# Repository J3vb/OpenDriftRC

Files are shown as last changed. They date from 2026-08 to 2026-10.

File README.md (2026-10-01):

<p align="center">
  OpenDrift
</p>

OpenDrift is an open source drift gyro for RC drift cars, built around the Waveshare ESP32-S3 Touch AMOLED 1.64 board. It reads steering, throttle, and optional gain channels from a receiver, mixes driver steering with gyro correction, outputs steering and optional throttle signals, and exposes tuning through both the onboard touch UI and a WiFi web configurator.

OpenDrift v1.0 uses a dedicated selectable-rate control task, a single gyro filter, continuous yaw prediction, throttle-informed load-change prediction, and non-accumulating quiet-drift reference feedback. The goal is to make gyro setup less of a black box while keeping the active control path small enough to reason about.

See the current [Technical Tuning Reference](OpenDrift/docs/Tuning.md) for the setup order, symptom table, surface-profile workflow, and findings from real track testing. The public [tuning guide](https://opendriftrc.com/tuning/) provides the shorter trackside workflow.

## Install Firmware

Visit [opendriftrc.com](https://opendriftrc.com) for the project overview, [wiring reference](https://opendriftrc.com/wiring/), and Open Beta firmware. The [browser installer](https://opendriftrc.com/flash/) provides current AMOLED images with either PWM or CRSF receiver support, without an account, source compilation, or command-line tools. Historical round-display releases remain available but are frozen.

## Current Features

- ESP32-S3 firmware using PlatformIO and Arduino.
- 280 x 456 AMOLED touch UI with swipeable pages and a permanent built-in
  background fallback.
- Up to 16 persistent custom AMOLED backgrounds, selectable from the display
  or web configurator. JPG, PNG, and WebP images can be converted locally at
  [opendriftrc.com/backgrounds](https://opendriftrc.com/backgrounds/).
- Persistent AMOLED theme engine with light/dark text, seven accent palettes,
  and background-aware translucent control panels, based on work contributed
  by [J3vb](https://github.com/J3vb).
- Dedicated 250 Hz or 333 Hz IMU/control/steering task isolated from UI, WiFi, and logging work.
- Continuous yaw-acceleration prediction with throttle-informed look-ahead.
- Quiet-drift reference feedback that yields to driver steering and throttle changes.
- Receiver steering input.
- Optional receiver throttle sensing with automatic Performance Mode behavior.
- Receiver gyro gain input.
- Selectable GPIO 18 gyro-gain input or throttle passthrough output.
- Servo output with center, reverse, and travel settings.
- Servo quiet band for direct-drive steering buzz.
- Physical servo endpoint calibration for max left, center, and max right.
- Separate radio steering travel limit.
- Separate servo reverse and gyro reverse.
- Gyro tuning:
  - gain
  - deadband
  - maximum correction
  - smoothing
  - Drift Memory and limit
  - Hold Assist
  - Prediction
  - Countersteer Assist
  - Transition Speed
  - Driver Priority
  - Anti Wobble
- Up to 12 persistent named surface/driving profiles.
- Scrollable trackside profile selection on both displays.
- Do-nothing signal-loss behavior when steering input is lost.
- WiFi access point.
- Browser-based web configurator.
- Non-blocking PSRAM blackbox logging with controller, prediction, throttle, notch, chassis-motion, and correction telemetry.
- Persistent settings stored in ESP32 preferences.
- Transition Speed adjustment centered at the neutral baseline of `50`.
- Driver Priority adjustment that yields fast direct gyro gain as steering input increases; default `0` preserves the established response.
- Phase-aware Anti Wobble notch with a track-tested default of `50`.
- Separate PWM and full-duplex CRSF targets for Waveshare AMOLED V1 and V2.
- Full-duplex CRSF steering, throttle, gain, link statistics, parameter
  telemetry, neutral failsafes, and [EdgeTX tuning](https://github.com/doublej380-pixel/OpenDriftRC/releases/download/v1.0.8/OpenDrift.lua).
- CRSF channel routing to accessory PWM outputs: GPIO 1–8 on AMOLED V1 and
  GPIO 3–8 on AMOLED V2.

## Hardware Routing

### Supported Boards

The **Waveshare ESP32-S3 Touch AMOLED 1.64** is the final and primary OpenDrift hardware target. New development, UI work, and release testing target this board.

Waveshare ships V1 and V2 revisions that require different firmware. V1 has its version silkscreen at the top of the PCB and uses LCD_CS on GPIO 9. V2 has the silkscreen beside the right-side pin headers and uses LCD_CS on GPIO 46. Select the exact revision in the web flasher.

The older Waveshare 1.28-inch round display build is deprecated and frozen. Its PlatformIO environment and implementation remain in the repository for experimentation, but no new firmware releases or feature-parity work are planned.

AMOLED V1 and the Round board use this PWM pinout:

| Signal | GPIO | Direction | Notes |
| --- | ---: | --- | --- |
| Receiver steering / servo in | 15 | Input | Standard RC PWM input |
| Receiver throttle / throttle in | 16 | Input | Throttle sensing and blackbox input |
| Steering servo / servo out | 17 | Output | Stabilized steering command |
| Gain input / throttle output | 18 | Selectable | Gain-channel input by default, or throttle passthrough output |

GPIO 18 cannot provide throttle output and read receiver gain at the same time.
To keep throttle sensing and gain adjustment, split the receiver throttle
signal to GPIO 16 and the ESC rather than plugging the ESC into OpenDrift.

Make sure the receiver, ESP32 board, and servo power system share ground.

AMOLED V2 keeps receiver steering on GPIO 15 and throttle on GPIO 16, but moves steering output to GPIO 1 and the switchable gain/throttle connection to GPIO 2. Do not use GPIO 17/18 for OpenDrift signals on V2; Waveshare connects those pins to IMU_INT2 and TP_INT.

CRSF targets repurpose the receiver pins:

| Signal | GPIO | Direction | Notes |
| --- | ---: | --- | --- |
| CRSF receiver TX | 17 | Input | Native CRSF channel and link frames |
| CRSF receiver RX | 18 | Output | Full-duplex parameter telemetry |
| Steering servo / servo port | 15 | Output | Selectable 250/333 Hz servo PWM |
| ESC throttle / throttle port | 16 | Output | Standard 50 Hz ESC PWM with active-neutral failsafe |

AMOLED V2 instead uses GPIO 1 for CRSF RX and GPIO 2 for CRSF TX while retaining GPIO 15 steering-servo output and GPIO 16 ESC output. All CRSF targets use the same full-duplex implementation and the
separate `OpenDriftCRSF` settings namespace and do not overwrite a PWM tune.

CRSF builds can also mirror any receiver channel to accessory outputs from the
WiFi web configurator. AMOLED V1 exposes GPIO 1–8; AMOLED V2 exposes GPIO 3–8
because GPIO 1/2 carry CRSF. Each enabled pin emits standard 50 Hz receiver PWM
and returns to 1500 microseconds when the CRSF link is lost. These are 3.3 V
signal outputs only: power lights and accessories separately and share ground.

Throttle sensing is not required for basic stabilization, but it is strongly recommended. With the throttle signal connected, OpenDrift can release settled-drift features during power changes instead of inferring those events from yaw alone. Treat it like a sensored-motor cable: the fallback works without it, while Performance Mode has substantially better phase awareness.

The servo should be powered from a suitable BEC or ESC receiver rail. Do not rely on the ESP32 board to power a steering servo. A DIY installation must feed the display/development board regulated 5 V, never an unregulated or 6 V-plus BEC output. The OpenDrift daughter boards under development include an onboard regulator. ESP32-S3 GPIOs are 3.3 V signal pins and are not 5 V tolerant.

## Build And Upload

The firmware project is in:

`OpenDrift/`

## Custom AMOLED Backgrounds

OpenDrift keeps the built-in galaxy image in firmware and can additionally
store up to 16 user backgrounds in the board's FFat partition. Custom images
must be 456 x 280 raw RGB565 files; the browser-based
[background converter](https://opendriftrc.com/backgrounds/) creates the exact
format locally from JPG, PNG, or WebP files.

To install one, join the gyro's `OpenDrift` WiFi network, open
`http://192.168.4.1`, and use the **AMOLED Backgrounds** card. Uploaded images
can be selected or deleted there, and can also be selected from the
**Backgrounds** page on the AMOLED display. Keep the car stationary while an
image is being written to flash. Leaving the selection on **Built-in** uses the
factory background and consumes no additional storage.

Build with PlatformIO:

```sh
pio run
```

The default environment is `waveshare_amoled_164`. Build or upload it explicitly with:

```sh
pio run -e waveshare_amoled_164
pio run -e waveshare_amoled_164 -t upload
```

The custom PlatformIO board definition is included at `OpenDrift/boards/waveshare_amoled_164.json`.

AMOLED V2 uses separate targets:

```sh
pio run -e waveshare_amoled_164_v2
pio run -e waveshare_amoled_164_v2_crsf
```

The frozen round-board environment remains available for local experimentation:

```sh
pio run -e waveshare_128
```

CRSF builds are intentionally separate:

```sh
pio run -e waveshare_amoled_164_crsf
```

Both supported targets enable full-duplex CRSF, GPIO 16 ESC output, and neutral-hold arming. Telemetry uses GPIO 18 on AMOLED V1 and GPIO 2 on AMOLED V2.

Main dependencies are managed in `OpenDrift/platformio.ini`:

- SensorLib
- LovyanGFX
- ESP32Servo
- CST816S (deprecated round-board build only)

## First Power-On

On boot, OpenDrift initializes:

1. Display
2. Settings
3. IMU
4. Servo output
5. Receiver inputs
6. Touch
7. Gyro calibration
8. WiFi, if enabled
9. UI

Keep the car still during startup so gyro calibration can capture a clean yaw-rate offset.

## Onboard UI Pages

Swipe left/right to move between pages.

### Main

Shows the current gyro gain and provides:

- `- / +`: adjust stored gain when radio gain input is not overriding it.
- `CAL`: recalibrate gyro offset. Use this when the car is sitting still and the gyro seems biased.

### Core

Primary correction limits:

- `Deadband`: yaw-rate zone ignored around zero.
- `MAX CORRECTION`: maximum gyro movement across the full calibrated endpoint-to-endpoint steering span. `50%` equals center-to-endpoint authority; `100%` can override one endpoint to the other.
- `GYRO REV`: reverses only the gyro correction direction.

Use `GYRO REV` when normal steering direction is correct, but the gyro counter-steers the wrong way.

### Response

Fast controller behavior:

- `SMOOTHING`: the software yaw low-pass; `0.00` bypasses it completely.
- `GYRO LPF`: QMI8658 hardware filtering at `24 Hz`, lower-latency `120 Hz`, or `Off` for controlled testing.
- `PREDICTION`: continuous yaw-acceleration look-ahead.
- `SERVO QUIET`: suppresses very small physical servo-command changes.

### Assistance

Slow quiet-drift behavior:

- `COUNTERSTEER`: chooses how much additional steady countersteer OpenDrift carries. Zero preserves the driver-led base response; higher values reduce the steering load on the driver without increasing fast yaw damping.
- `HOLD ASSIST`: controls how firmly the quiet-drift reference is retained.
- `DRIFT MEMORY`: feedback for deviation from a learned quiet-drift reference.

The Drift Memory limit remains available in the web configurator as an advanced limit.

### Tail Response

`TAIL SPEED` is tuned separately from the core v1.0 controls:

- `50` is the Open Beta baseline response.
- Below `50` adds damping during deliberate entries and transitions.
- Above `50` releases some damping so the chassis can rotate faster.
- The effect is reduced in a settled drift and cannot reverse gyro correction.

Keep it at `50` unless deliberately collecting same-car experimental A/B data.

`SMOOTH` is intentionally inverted from raw filter math: higher numbers mean more smoothing and slower gyro response.

Deadband is applied as a soft deadband. Small yaw noise is still ignored, but correction fades in from zero instead of jumping as soon as yaw crosses the deadband value.

Conservative first-power values:

| Setting | Start |
| --- | ---: |
| Gain | 1.50 |
| Deadband | 4.0 |
| Max correction | 100% |
| Smoothing | 0.01 |
| Countersteer Assist | 100 |
| Driver Priority | 0 |
| Drift memory | 0.00 |
| Memory limit | 80 |
| Hold Assist | 0 |
| Prediction | 0 |

Tune symptoms:

| Symptom | Try |
| --- | --- |
| Weaves left/right driving straight | Increase deadband or lower gain |
| Initial response is strong but runs out of authority | Raise Max Correction carefully |
| Fast response overshoots | Add Prediction in steps of 5 |
| Prediction makes transitions nervous | Lower Prediction |
| Car is stable but the driver carries too much countersteer | Raise Countersteer Assist in steps of 10 |
| Gyro feels too hands-on during a settled drift | Lower Countersteer Assist |
| High gain feels restrictive near full steering | Add Driver Priority in steps of 5; start below 20 |
| Long drift slowly wanders | Add Hold Assist, then minimal Drift Memory |
| Transition carries the old drift | Lower Hold Assist or Drift Memory |
| Mid-drift wheel oscillation | Lower gain first; verify servo and chassis |
| Feels slow or lazy | Lower smoothing slightly or raise gain |

### Radio

Live receiver monitor:

- Steering pulse and signal state.
- Gain pulse and signal state.
- Current gain value.
- Calibration values.
- Position bars for steering and gain.

Use this page to confirm the receiver is connected and moving through a sensible range.

In a CRSF build the monitor shows channel 1 steering, channel 2 throttle, and
channel 3 gain decoded from the digital link.

### Steering

Steering output setup:

- `TRV`: scales driver steering input without reducing gyro correction authority.
- `REV`: reverses physical servo direction.
- Swipe once more to open the dedicated **Physical Endpoints** page.

### Physical Servo Endpoints

The calibration page uses three large capture buttons. Each button starts red
and turns green after it has captured the servo's actual physical PWM position:

- `MAX LEFT`: position the wheels at their safe physical left stop, then capture it.
- `CENTER`: capture the transmitter at neutral.
- `MAX RIGHT`: position the wheels at their safe physical right stop, then capture it.

OpenDrift saves the calibration after all three physical positions are captured
on opposite sides of center. The saved endpoints become the final asymmetric
servo map and hard clamp, so neither the driver nor gyro can push through them.

CRSF users can perform the same three captures from the EdgeTX `OpenDrift.lua`
tool. Calibration state is persistent and shared: completing it on the radio
turns the AMOLED buttons green, while completing it on the display updates the
radio's `Endpoints` status to `YES`.

Suggested calibration flow:

1. Set servo direction first, then use steering/transmitter endpoint adjustment to position the wheels at the safe physical left stop and tap `MAX LEFT`.
2. Release steering to neutral and tap `CENTER`.
3. Position the wheels at the safe physical right stop and tap `MAX RIGHT`.
4. Confirm all three buttons are green and the page says `SAVED - TAP TO RESET`.
5. Return to Steering and verify the wheels remain inside both saved physical stops.

Changing `REV`, Servo Center, or Servo Travel after calibration deliberately
clears the saved calibration because those changes alter the physical output map.

Servo reverse and gyro reverse are separate on purpose:

- Use `REV` on the Steering page when driver steering moves the wheels backward.
- Use `GYRO REV` on the Gyro page when driver steering is correct but gyro correction is backward.

Physical endpoint calibration and steering travel are separate on purpose:

- Use `MAX LEFT`, `CENTER`, and `MAX RIGHT` to set the servo's physical output limits.
- Use `TRV` to scale driver steering without reducing gyro authority.
- Use Max Correction to select how much of the calibrated physical range the gyro may command.

### WiFi

Shows the network name, WiFi state and connected client count.

- `WIFI ON/OFF`: toggles the access point.

When WiFi is enabled, connect to the network shown at the top of the page and
open `http://192.168.4.1/`. The password is `opendrift`.

- A unit on the default name broadcasts `OpenDrift-XXXX`. The last four
  characters are unique to the board, so several cars at one track show up as
  separate networks. A custom name from the web configurator is used as is.
- At startup, OpenDrift picks the quietest of channels 1, 6 and 11. It uses a
  narrow 20 MHz channel so 2.4 GHz RC links clash with it less often.
- WiFi stays on for at least 3 minutes after power-on while waiting for the
  first phone. After that, the auto-off timeout applies.
- Phones may warn that the network has no internet. Choose to stay connected,
  or turn off mobile data while configuring.

### System

Basic firmware/system information. Tap the GPIO 18 mode button to switch between `GAIN INPUT` and `THROTTLE OUT`.

### Profiles

The Profiles page lists the driving profiles created in the web configurator. Tap a profile to activate its complete driving tune. Swipe vertically when more than four profiles exist; the list supports up to 12 profiles.

Profiles save gain, deadband, max correction, smoothing, Prediction, Countersteer Assist, Driver Priority, Hold Assist, Drift Memory and its limit, and radio steering travel. Trackside adjustments automatically save back to the active profile.

Hardware and installation settings remain global, including gyro/servo direction, physical steering endpoints, servo center and travel, WiFi, logging, and GPIO mode. Switching surfaces therefore cannot disturb the car's physical setup.

### Control and servo rate

OpenDrift defaults to **250 Hz** for broad digital-servo compatibility. **333 Hz** reduces the output interval from 4 ms to about 3 ms and can sharpen a fast supported servo, but it must only be used when the servo manufacturer explicitly rates the servo for 333 Hz operation. An unsupported update rate can cause heat, buzzing, erratic steering, or servo damage.

The setting is global and appears on the AMOLED System page, in the web configurator, and in the CRSF/EdgeTX parameter list. Restart OpenDrift after changing it so both the control task and steering PWM start at the selected rate.

## Web Configurator

When WiFi is enabled, OpenDrift starts a web configurator at:

`http://192.168.4.1/`

Current web settings:

- Create named driving profiles from the current tune
- Activate or delete existing profiles
- Gyro gain
- Channel 3 gain minimum / maximum (`0.00-6.00`)
- Deadband
- Reverse gyro correction
- Max correction
- Smoothing
- Prediction strength
- Transition Speed
- Driver Priority
- Anti Wobble
- Drift memory
- Memory limit
- Hold Assist
- Servo reverse
- Servo center
- Servo travel
- Servo quiet band
- Steering max left / center / max right
- Radio steering travel
- Gain channel low / high
- GPIO 18 gain-input or throttle-output mode
- WiFi enabled on boot
- WiFi auto-off timeout
- Blackbox logging enabled
- Raw pitch, roll, acceleration, and surface-disturbance telemetry for chassis analysis

The web page also shows the active profile, live receiver pulse values for steering, throttle, and gain, plus the active GPIO 18 mode.

Use the web configurator when you want to make several changes quickly. Use the onboard UI when tuning trackside without a phone or laptop.

## Onboard Blackbox Log

OpenDrift records fixed-size blackbox samples into a 4 MB circular PSRAM buffer at about 20 Hz while steering receiver signal is present.

Blackbox logging is disabled by default. Enable `Onboard logging` in the web configurator only when you want to collect data, then save settings.

No flash or filesystem writes occur while driving. Once the circular buffer is full, the oldest records are overwritten so the newest behavior remains available. Download the CSV before removing power because PSRAM is volatile.

The web configurator shows the current log size and provides:

- `Download CSV`
- `Clear RAM Log`

Log rows include:

- Time
- Raw yaw rate
- Filtered yaw rate
- Roll and pitch gyro rates (`gyro_x_dps`, `gyro_y_dps`)
- Raw X/Y/Z acceleration in g
- Total acceleration magnitude and high-frequency acceleration delta
- A filtered `surface_disturbance` score from `0.0` to `1.0`
- Requested gyro correction before Max Correction
- Limited gyro correction after Max Correction
- Applied gyro correction after the driver/gyro steering mix
- Correction saturation state
- Steering input and calibrated steering command
- Servo output
- Servo quiet band
- Throttle input
- Gain input and active gain
- Active deadband, max correction, smoothing, Prediction, Countersteer Assist, Driver Priority, Hold Assist, Drift Memory, and memory limit
- Driver Priority scale and effective live direct gain
- Predicted yaw, quiet-drift reference, reference error, steady countersteer contribution, and memory correction
- Driver steering activity and throttle-prediction blend
- Controller phase (`0` idle, `1` entry, `2` settled, `3` transition) and reference-lock blend
- Anti Wobble notch depth, isolated residual, tracked notch frequency, transition-authority blend, and throttle-lift blend
- Steering/throttle/gain signal state and GPIO 18 mode

Suggested test workflow:

1. Connect to the `OpenDrift` WiFi network.
2. Open `http://192.168.4.1/`.
3. Enable onboard logging if it is off, then save settings.
4. Tap `Clear RAM Log`.
5. Drive the car.
6. Reconnect to WiFi and tap `Download CSV` before resetting or removing power.

The CSV can be pasted into a spreadsheet or plotted to see whether the car spun because of delayed correction, overcorrection, max correction saturation, noisy yaw, or steering/radio behavior.

`surface_disturbance` still combines sudden acceleration-vector changes, roll/pitch rate, and low-g unloading indicators for analysis. OpenDrift v1.0 logs it but does not currently apply terrain correction.

## Gyro Algorithm Overview

OpenDrift v1.0 runs this path at the selected 250 Hz or 333 Hz rate:

1. Read receiver steering, throttle, and IMU yaw.
2. Subtract calibrated gyro offset and apply soft deadband.
3. Apply the selected hardware gyro LPF and optional software yaw low-pass.
4. Estimate short-horizon yaw from filtered yaw acceleration.
5. Extend that horizon when throttle predicts application or a longer off-throttle load change.
6. Shape damping briefly during deliberate direction changes without changing the hard correction ceiling.
7. Apply the phase-aware Anti Wobble notch around the tracked 2.5-3.6 Hz wheel-resonance band while preserving slow chassis yaw and useful response outside that band.
8. Convert predicted yaw directly into correction with Gain.
9. Learn a slow yaw reference while driver steering and throttle are quiet.
10. Add optional Countersteer Assist from the slow learned reference only.
11. Apply Drift Memory only to error from that reference.
12. Prevent memory from pushing farther into correction saturation.
13. Limit signed gyro movement to the configured full-span Max Correction
    percentage, then mix it with driver steering and clamp the combined command.
14. Apply the calibrated physical endpoint map as the final hard servo limit.

Driver steering activity and throttle changes make the slow reference yield
immediately. Neither disables the fast direct damping path.

## Signal Loss Behavior

The standard PWM builds retain the existing do-nothing behavior: if steering
input disappears, OpenDrift does not send a new servo command.

This leaves the servo at the last commanded position. It is intentionally a simple do-nothing behavior while failsafe strategy is still being evaluated.

The full CRSF build has deterministic behavior because all channels share one
link state. A channel frame older than 50 ms centers steering and commands
neutral throttle. Throttle remains locked until a valid link has held neutral
for 500 ms after boot or reconnection.

## Tuning

Use the [Technical Tuning Reference](OpenDrift/docs/Tuning.md) rather than tuning every setting at once. The most important lessons from development are:

- Establish a mechanically sound car before blaming the gyro.
- Set the servo's internal anti-wobble only as high as it can run without buzzing; high servo torque/power can amplify internal oscillation.
- Treat Gain as the primary surface-dependent setting and store each surface in a profile.
- Tune entries with Gain, Max Correction, and Smoothing before adding slow reference feedback.
- Add Prediction in small steps only after the direct response is understood.
- Use Hold Assist for sustained-drift reference retention, then add only the minimum Drift Memory required.
- Use Countersteer Assist to choose driver-led versus gyro-led settled drifts without retuning Gain.
- Connect throttle sensing so OpenDrift can anticipate power and load changes.

OpenDrift v1.0 is the first public controller. Start from the conservative
values in the tuning reference and save proven surface setups as profiles.

## Future Work

- **Servo resonance calibration:** add a stationary calibration mode that sweeps a small steering command across a safe frequency range and captures high-rate chassis IMU data. Because the servo is rigidly mounted to the chassis, its buzz and self-oscillation should be measurable without another sensor. The first version should compare vibration energy, dominant resonances, settling, and left/right behavior to help evaluate internal servo anti-wobble, torque, power, and response settings and recommend OpenDrift quiet-band and correction-rate settings. Command shaping or resonance compensation should only follow after repeatable measurements show that it can reduce vibration without adding harmful control-loop delay.

## Project Layout

Important folders:

- `OpenDrift/src/main.cpp`: main firmware loop and control mixing.
- `OpenDrift/lib/GyroController`: gyro filtering and correction generation.
- `OpenDrift/lib/RadioInput`: receiver PWM input capture.
- `OpenDrift/lib/CrsfInput`: bounded native CRSF frame decoding and telemetry.
- `OpenDrift/lib/CrsfParameterDevice`: bidirectional CRSF settings device.
- `OpenDrift/lib/EscOutput`: dedicated 50 Hz LEDC throttle output.
- `OpenDrift/lib/Servo`: servo output wrapper.
- `OpenDrift/lib/Settings`: persistent settings.
- `OpenDrift/lib/UI`: onboard touch UI.
- `OpenDrift/lib/WebConfigurator`: web settings page.
- `OpenDrift/lib/WIFIManager`: WiFi access point control.
- `OpenDrift/lib/Backgrounds`: persistent AMOLED background storage and
  recovery.
- `OpenDrift/docs/Tuning.md`: complete tuning and blackbox interpretation guide.
- `OpenDrift/docs/CRSF-Experimental.md`: CRSF wiring, failsafes, and validation
  workflow.
- `OpenDrift/radio/edgetx`: source for the [OpenDrift EdgeTX tuning tool](https://github.com/doublej380-pixel/OpenDriftRC/releases/download/v1.0.8/OpenDrift.lua).
- `OpenDrift/assets/backgrounds`: built-in AMOLED fallback background data.
- `OpenDrift/boards`: custom PlatformIO board definitions.

## License

See `LICENSE`.

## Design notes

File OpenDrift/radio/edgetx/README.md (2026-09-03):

# [OpenDrift EdgeTX tool](https://github.com/doublej380-pixel/OpenDriftRC/releases/download/v1.0.8/OpenDrift.lua)

This tool supports the AMOLED V1 and V2 **full-duplex** CRSF firmware targets:
`waveshare_amoled_164_crsf` and `waveshare_amoled_164_v2_crsf`.

Download [`OpenDrift.lua`](https://github.com/doublej380-pixel/OpenDriftRC/releases/download/v1.0.8/OpenDrift.lua), copy it to `SCRIPTS/TOOLS/OpenDrift.lua` on the radio SD card,
then launch **OpenDrift** from the [EdgeTX Tools menu](https://github.com/doublej380-pixel/OpenDriftRC/releases/download/v1.0.8/OpenDrift.lua).

CRSF wiring for the full-duplex firmware:

- Receiver TX to OpenDrift GPIO 17
- Receiver RX to OpenDrift GPIO 18
- Receiver and OpenDrift grounds connected

Use the roller to select a setting, press it to enter edit mode, rotate to
change the value, and press again to finish. Changes are applied live and are
saved by OpenDrift's normal delayed settings writer. A successful radio write
also requests an immediate refresh of the current OpenDrift display page.

Physical endpoint calibration sets the servo's hard output limits and is shared with both displays. The header and
`Endpoints` row show `NO`, `PARTIAL`, or `YES`. To calibrate from the radio:

1. Hold the steering at its safe physical left stop, select `Capture Left`, and press Enter.
2. Release to neutral, select `Capture Center`, and press Enter.
3. Hold full right, select `Capture Right`, and press Enter.

The action rows show `HOLD POSITION + ENTER` while selected. After all three
valid captures, the status changes to `YES` and the AMOLED calibration buttons
turn green. Capturing on the AMOLED page updates the radio status as well.
Use `Reset Cal` before expanding or replacing existing endpoints.

`Active Gain` follows CRSF channel 3 live. The tool shows a reminder that
channel 3 overrides gain changes made elsewhere while its signal is valid; the
stored profile gain remains the fallback used without that gain signal.
`CH3 Gain Min` and `CH3 Gain Max` map the full Channel 3 control movement to
the desired gyro-gain range. The default remains `0.50` to `3.00`, while both
the controller and Channel 3 mapping support values up to `6.00`.

The tool exposes the gyro and steering values: Active Gain, Channel 3 gain range, Deadband, Max Correction,
Smoothing, Gyro LPF, Drift Memory, Memory Limit, Hold Assist, Countersteer, Transition
Speed, Prediction, Anti Wobble, Servo Quiet, Steering Travel, physical endpoints,
Servo Travel, Servo Center,
Servo Reverse, and Gyro Reverse. It also assigns CRSF channel 1–16 or OFF to
GPIO 1–8 on AMOLED V1 and GPIO 3–8 on AMOLED V2. GPIO 1/2 display `RES` on V2
because those pins carry the CRSF UART.

`Gyro LPF` selects the QMI8658 hardware filter: `24 Hz` is the original
low-bandwidth mode, `120 Hz` reduces sensor phase delay, and `Off` bypasses the
sensor LPF. `Smoothing 0.00` is a true software-filter bypass. Blackbox logs
record the active selection in `gyro_lpf_mode` as 0, 1, or 2 respectively.

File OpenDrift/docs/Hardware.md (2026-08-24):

# OpenDrift Hardware Notes

## Primary board

The final supported target is the Waveshare ESP32-S3 Touch AMOLED 1.64. The older Waveshare 1.28-inch round display is deprecated and frozen; its existing source remains available for experimentation but receives no new releases or feature-parity work.

The AMOLED board has incompatible V1 and V2 revisions. V1 is marked at the top of the PCB and uses LCD_CS GPIO 9. V2 is marked beside the right-side headers and uses LCD_CS GPIO 46. V2 also connects IMU_INT2 to GPIO 17 and TP_INT to GPIO 18, so OpenDrift does not use GPIO 17/18 for external signals on V2.

## QMI8658 IMU

Both boards use the QMI8658 six-axis IMU. OpenDrift uses body Z as yaw and records body X/Y gyro plus all three accelerometer axes for terrain and load-transfer analysis.

| Board | SDA | SCL |
| --- | ---: | ---: |
| AMOLED 1.64 | GPIO 47 | GPIO 48 |
| Round 1.28 | GPIO 6 | GPIO 7 |

The current board orientation reports clockwise rotation as positive Z and counter-clockwise rotation as negative Z. Always verify correction direction by rotating the complete car before driving.

## PWM receiver and servo routing

AMOLED V1 and the Round build use the same PWM pinout:

| Signal | GPIO | Direction |
| --- | ---: | --- |
| Receiver steering / servo in | 15 | Input |
| Receiver throttle / throttle in | 16 | Input |
| Steering servo / servo out | 17 | Output at selectable 250/333 Hz |
| Gain input or throttle passthrough | 18 | Selectable |

GPIO 18 can be a receiver gain input or an ESC throttle output, but not both.
To retain throttle sensing and receiver gain control simultaneously, split the
receiver throttle signal between GPIO 16 and the ESC instead of connecting the
ESC to GPIO 18.

AMOLED V2 PWM uses GPIO 15 steering input, GPIO 16 throttle input, GPIO 1 steering-servo output, and GPIO 2 as the selectable gain input or throttle output.

## CRSF routing

AMOLED V1 and Round CRSF share this routing:

| Signal | GPIO | Direction |
| --- | ---: | --- |
| CRSF RX from receiver TX | 17 | Input |
| CRSF TX to receiver RX | 18 | Output |
| Steering servo / servo port | 15 | Output at selectable 250/333 Hz |
| ESC throttle / throttle port | 16 | Output at 50 Hz |

Both `waveshare_128_crsf` and `waveshare_amoled_164_crsf` enable the complete
full-duplex path. They remain separate from the normal PWM environments because
the GPIO routing and settings namespace differ.

AMOLED V2 CRSF uses GPIO 1 RX, GPIO 2 TX, GPIO 15 steering-servo output, and GPIO 16 ESC output. Its targets are `waveshare_amoled_164_v2` and `waveshare_amoled_164_v2_crsf`.

CRSF channel mapping is channel 1 steering, channel 2 throttle, and channel 3
gain. A stale channel frame centers steering and commands neutral throttle.
Throttle output requires a valid link and a 500 ms neutral hold
before arming.

## CRSF auxiliary channel outputs

The AMOLED CRSF builds can mirror any CRSF channel from 1 through 16 to a
standard 50 Hz receiver-style PWM signal. Assign each pin independently in the
WiFi web configurator under **Auxiliary Channel Outputs**.

| Board | Available auxiliary GPIOs |
| --- | --- |
| AMOLED V1 CRSF | GPIO 1–8 |
| AMOLED V2 CRSF | GPIO 3–8 |

GPIO 1/2 are unavailable on V2 because they carry the CRSF UART. Disabled pins
remain inputs. Enabled pins output the selected channel and command 1500
microseconds when the CRSF link is lost. GPIOs provide a 3.3 V signal only;
lights, controllers, or other accessories require their own appropriate power
supply and a common ground with OpenDrift.

## Throttle sensing

Throttle sensing is electrically optional and automatically falls back when no valid PWM signal exists. It is strongly recommended for OpenDrift v1.0 because it announces power and chassis-load changes, temporarily extends yaw prediction, and makes the slow drift reference yield before stale feedback can fight the transition.

Only the receiver signal and a shared ground are required. OpenDrift does not power the receiver or ESC through the throttle input.

## Power and grounding

The receiver, ESP32 board, and servo/ESC system must share ground. Power the steering servo from an appropriate BEC or receiver rail; do not draw servo current through the ESP32 board.

Feed a DIY OpenDrift display/development board with regulated 5 V on its 5 V
input. Do not connect a 6 V or higher BEC directly to that input. The OpenDrift
daughter boards under development include an onboard regulator so the builder
does not need to add a separate 5 V regulator. ESP32-S3 GPIOs remain 3.3 V logic
and are not 5 V tolerant; every external GPIO is a 3.3 V signal only.

Fast drift servos can draw large transient current and can oscillate from their own internal settings. Verify servo stability directly from the receiver before diagnosing the gyro.

OpenDrift defaults to 250 Hz for broad digital-servo compatibility. The optional 333 Hz control and servo rate is only for servos whose manufacturer explicitly supports 333 Hz. Restart the board after changing the rate.

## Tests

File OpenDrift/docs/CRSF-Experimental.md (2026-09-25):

# CRSF Open Beta builds

These are separate firmware targets for direct CRSF control. Choose the CRSF
variant only when the receiver is wired through OpenDrift.

## Build target

- `waveshare_amoled_164_crsf`: full-duplex AMOLED target
- `waveshare_amoled_164_v2_crsf`: full-duplex AMOLED V2 target

The Waveshare round-display target is frozen and is no longer part of current
builds or releases.

CRSF settings are stored in the separate `OpenDriftCRSF` NVS namespace, so
they do not overwrite the corresponding PWM tune.

All targets use the complete path: bounded CRSF receive processing, parameter
telemetry, GPIO 16 ESC PWM, deterministic neutral behavior, and the
[EdgeTX tuning tool](https://github.com/doublej380-pixel/OpenDriftRC/releases/download/v1.0.8/OpenDrift.lua). The round target proved stable with a SpeedyBee SB Nano at
the MT12's F1000 packet rate after the receive loop was given an explicit byte
budget; the AMOLED target now uses the same CRSF implementation.

## SpeedyBee SB Nano wiring

Wire the receiver signals crossed, as required by a UART:

| SpeedyBee SB Nano | OpenDrift board | Purpose |
|---|---|---|
| TX | GPIO 17 | CRSF data into OpenDrift |
| RX | GPIO 18 | CRSF data/parameter telemetry from OpenDrift |
| GND | GND | Common signal ground |
| 5V | Vehicle BEC 5V | Receiver power |

That table applies to AMOLED V1. AMOLED V2 uses GPIO 1 for receiver
TX into OpenDrift and GPIO 2 for receiver RX/parameter telemetry. Do not use
GPIO 17/18 for external signals on V2 because Waveshare connects them to
IMU_INT2 and TP_INT.

OpenDrift outputs are:

| OpenDrift board | Connect to | Signal |
|---|---|---|
| GPIO 15 | Steering servo signal | Selectable 250/333 Hz PWM |
| GPIO 16 | ESC throttle signal | 50 Hz PWM |

Do not power the servo or ESC motor from the display board. A DIY display-board
installation needs a regulated 5 V supply; do not feed a 6 V or higher BEC
directly into the board. The daughter boards under development include their
own regulator. Use the vehicle's normal power wiring, make sure every device
shares ground, and verify the connector labels rather than relying on wire
colour or position.

## Initial channel map

- CRSF channel 1: steering
- CRSF channel 2: throttle
- CRSF channel 3: gyro gain

Channel values are decoded from native 11-bit CRSF frames. Existing steering
calibration, travel, gyro processing, web status, and blackbox logging consume
those decoded values through the same interfaces used by the PWM build.

## Auxiliary channel outputs

The local WiFi configurator can assign CRSF channel 1–16 independently to
GPIO 1–8 on AMOLED V1. AMOLED V2 offers GPIO 3–8 because GPIO 1/2 are used by
the CRSF UART. Outputs use standard 50 Hz receiver PWM and command 1500
microseconds on signal loss. They are 3.3 V signal pins, not accessory power
outputs; use external power and a common ground for lights and controllers.

## Failsafes

- A CRSF channel frame older than 50 ms is treated as signal loss.
- Steering centers when the link is lost.
- GPIO 16 emits no throttle PWM until a valid link has held throttle within
  50 microseconds of center for 500 ms.
- If the link is lost, the full build commands neutral throttle immediately.
  Reconnection requires another neutral hold before live throttle passes.

## [EdgeTX parameter tool](https://github.com/doublej380-pixel/OpenDriftRC/releases/download/v1.0.8/OpenDrift.lua)

Download [`OpenDrift.lua`](https://github.com/doublej380-pixel/OpenDriftRC/releases/download/v1.0.8/OpenDrift.lua) and copy it to `SCRIPTS/TOOLS/OpenDrift.lua` on the radio SD
card, then open **OpenDrift** from the [EdgeTX Tools menu](https://github.com/doublej380-pixel/OpenDriftRC/releases/download/v1.0.8/OpenDrift.lua). The current tool reads
and writes the controller settings over full-duplex CRSF:

- saved gain, deadband, Max Correction percentage, and smoothing;
- Drift Memory, memory limit, Hold Assist, and Countersteer Assist;
- Transition Speed, Driver Priority, Prediction, Anti Wobble, Servo Quiet, Steering Travel, Servo Travel,
  and Servo Center;
- Servo Reverse and Gyro Reverse.
- shared physical servo endpoint-calibration status plus live left, center, and
  right capture actions and a Reset Cal action. Captures made from EdgeTX
  immediately update the AMOLED page, and display-side calibration is polled
  back into the radio tool.

Writes are acknowledged over CRSF, applied live, saved through the normal
delayed settings writer, and request an immediate redraw of the current gyro
screen.

The same tool also exposes the auxiliary output map. AMOLED V1 can assign
GPIO 1–8 to CRSF channel 1–16 or Off. AMOLED V2 can assign GPIO 3–8; GPIO 1/2
show as reserved because they carry the CRSF UART.

## Problems found during validation

- An F1000 receiver can keep the UART continuously non-empty. CRSF receive work
  is bounded per update so it cannot starve the selected-rate controller.
- Using the general servo allocator for simultaneous 250 Hz steering and 50 Hz
  throttle exhausted or cross-routed ESP32 timing resources. `EscOutput` now
  owns a dedicated 14-bit LEDC channel for throttle.
- CRSF settings use the `OpenDriftCRSF` NVS namespace so switching firmware
  variants cannot overwrite a PWM profile.

## First bench test

1. Remove the motor pinion or disconnect the motor from the ESC.
2. Flash the CRSF environment matching the connected display board with only
   that board connected by USB.
3. Wire and power the receiver, then bind it to the MT12.
4. Open the USB serial monitor at 115200 baud. The five-second CRSF report
   should show increasing frame counts, low CRC errors, link quality, and
   `throttle=LOCKED`.
5. Confirm steering, throttle, and gain move in the web configurator.
6. Hold throttle neutral for 500 ms and confirm the report changes to
   `throttle=ARMED`.
7. Turn the transmitter off. Steering and throttle must return to neutral and
   the report must return to `throttle=LOCKED`.
8. Open the [EdgeTX tool](https://github.com/doublej380-pixel/OpenDriftRC/releases/download/v1.0.8/OpenDrift.lua), change one harmless value, and confirm both the radio
acknowledgement and gyro-screen refresh.

Only reconnect the motor after every applicable check passes.

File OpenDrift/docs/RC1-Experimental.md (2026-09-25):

# Experimental Transition Response

Transition Speed is a direction-change timing adjustment. Start at `50`.

Unlike the former gain-based response experiment, this adjustment slews the
gyro correction through a direction change without multiplying Gyro Gain.
Driver steering announces the transition and measured chassis yaw keeps the
timing stage active through the physical reversal. Values below 50 reverse
correction more slowly; values above 50 reverse it more quickly. Transition
Speed never changes the hard Max Correction ceiling. It does not command
rotation, reverse gyro direction, or change steady Countersteer Assist.

Transition prediction is also tapered while a direction change is in progress.
If acceleration prediction reaches the new yaw direction before the measured
chassis does, the controller now falls back to continuous measured-yaw damping
instead of briefly dropping correction to zero.

## First test

1. Keep the proven track profile unchanged and set Transition Speed to `50`.
2. Confirm that entries and transitions are predictable with the neutral path.
3. Test `25` for slower rotation and `75` for faster rotation using the same
   entries and transitions. The wide first comparison is intentional.
4. Work back toward `50` in steps of `5` or `10` once the preferred direction
   is obvious.
5. Capture a blackbox log at `50` and at the preferred experimental value.

Compare transition duration, peak yaw rate, overshoot after the direction
change, steering activity, `transition_speed_blend`,
`transition_authority_blend`, and `transition_prediction_scale`. Avoid changing
Gain, Prediction, Hold Assist, or Countersteer Assist during the comparison.

## Blackbox fields

- `transition_speed`: saved correction-reversal speed from 0-100; start at 50.
- `transition_speed_blend`: signed configured speed while transition timing is
  active. Negative values are slower; positive values are faster.
- `transition_slew_us`: actual correction from the gain-independent timing
  stage before Memory and Max Correction.
- `transition_authority_blend`: detected transition envelope from 0 to 1.
- `transition_prediction_scale`: multiplier applied to optional acceleration
  and throttle look-ahead. It approaches 0.25 during a full transition.

## Settled-drift residual damping

Blackbox runs 39 through 47 identified the remaining wheel wobble as a
closed-loop mode centered near 3.2 Hz. Broad residual suppression improved it
around strength 70, but higher values removed useful fast gyro damping and made
the car worse. Control now uses a narrow notch that starts at 3.2 Hz and slowly
tracks confirmed oscillation between 2.5 and 3.6 Hz whenever the car is settled
and driver input is quiet. A deliberate transition or strong steering input
freezes frequency tracking while retaining a shallow guard notch. Suppression
moves smoothly between the transition guard, entry depth, and full settled
depth instead of abruptly releasing the resonant band at each state change.

Anti Wobble is the only control. It defaults to `50`. At `0`, the notch is bypassed. Higher values
increase notch depth, up to the complete tracked-notch response at `100`. Slow
chassis yaw, fast corrections outside the wobble band, Countersteer Assist,
and Prediction remain active. The frequency detector and latch remain in the
blackbox as diagnostic telemetry but do not gate control.

- `hunt_residual_dps`: instantaneous yaw isolated by the tracked notch.
- `hunt_removed_us`: direct correction withheld from that residual.
- `hunt_consistent_half_cycles`: consecutive half-cycles agreeing on frequency.
- `hunt_latch`: remaining confirmed-event hold from 0 to 1.
- `anti_wobble`: saved Anti Wobble notch-depth setting from 0-100.
- `hunt_residual_envelope_dps`: continuous residual-energy diagnostic.
- `hunt_notch_center_hz`: slowly tracked center frequency currently applied
  by the dynamic notch.

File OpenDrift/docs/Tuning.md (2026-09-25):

# OpenDrift v1.0 Tuning

> **Technical reference:** This document records the complete tuning behavior
> and current test workflow. The shorter public guide is available at
> [opendriftrc.com/tuning](https://opendriftrc.com/tuning/).

OpenDrift v1.0 is a clean-sheet controller built from extensive track testing.
It uses a deliberately short control path so each adjustment has a clear job.

OpenDrift v1.0 runs the IMU, control calculation, and steering output in a dedicated
250 Hz or 333 Hz task. Display, touch, Wi-Fi, web configuration, and logging run outside
the control task. The steering servo output uses the same selected rate; throttle passthrough
remains 50 Hz.

## Mechanical baseline first

The controller cannot repair an unstable chassis or servo.

Before tuning:

- Confirm the servo is stable with its internal anti-wobble setting just below
  the point where it buzzes.
- Confirm the receiver has no hidden stability assistance.
- Check steering endpoints for binding.
- Establish sensible front toe, rear toe, camber, ride height, and damping.
- Verify the same chassis can drive cleanly with a known-good gyro.
- Calibrate steering and gyro direction with the wheels safely off the ground.

Open **Physical Endpoints** and position the wheels at their
safe physical full-left stop, neutral, and safe full-right stop before capturing
each point. Each target changes from red to green; do not drive until all
three are green and the page reports `SAVED - TAP TO RESET`. CRSF users can make
the same captures from `OpenDrift.lua`. Its `END: NO/PART/YES` status and the
AMOLED status use the same saved calibration and update each other.

Rear toe-in accidentally present during development made the car and controller
fight one another. Correcting the alignment materially improved both OpenDrift
and commercial gyros.

## v1.0 signal path

The active path is intentionally short:

1. Read receiver steering, throttle, and IMU yaw.
2. Apply deadband and one time-based yaw low-pass.
3. Estimate short-horizon yaw from filtered yaw acceleration.
4. Extend that prediction briefly when throttle announces a chassis-load
   change.
5. Hold a longer prediction envelope after throttle lift so off-throttle load
   changes do not arrive as a surprise.
6. Taper optional prediction during deliberate transitions so prediction does
   not run ahead of the physical yaw reversal.
7. Track and isolate the measured 2.5-3.6 Hz wheel-wobble band during a quiet
   settled drift, then use Anti Wobble to control notch depth while
   preserving slow chassis yaw and useful correction outside that band. A
   shallow guard remains during entry and transitions so the resonance cannot
   restart while frequency tracking is intentionally frozen.
8. Apply direct yaw correction using Gain.
9. While the driver and throttle are quiet, learn a slow drift reference.
10. Add optional Countersteer Assist from that slow reference.
11. Apply Drift Memory only to deviation from that reference.
12. Clamp correction with saturation-aware memory behavior.
13. Add correction to receiver steering and send it to the servo.

Driver steering activity and throttle changes make the slow reference follow
the car quickly. They do not disable the fast direct damping path.

## Active settings

| Setting | v1.0 behavior |
|---|---|
| Gain | Direct correction per degree/second of predicted yaw |
| CH3 Gain Min / Max | Maps the full Channel 3 knob or slider range to gain; defaults to `0.50` through `3.00` and supports up to `6.00` |
| Deadband | Removes very small corrected yaw near zero |
| Max Correction | Maximum gyro correction as a percentage of the full calibrated endpoint-to-endpoint steering span; `50%` is center-to-endpoint authority and `100%` can override one endpoint all the way to the other |
| Smoothing | Broad software yaw low-pass; `0.00` bypasses it and larger values add filtering and phase delay |
| Gyro LPF | QMI8658 hardware bandwidth: original 24 Hz, low-latency 120 Hz, or Off |
| Countersteer Assist | Adds slow settled-drift countersteer without increasing fast damping; `0` preserves the base response |
| Prediction | Continuous yaw-acceleration look-ahead from 0–100 |
| Hold Assist | Controls how slowly a quiet-drift reference follows yaw |
| Drift Memory | Feedback strength for error from the quiet-drift reference |
| Memory Limit | Maximum Drift Memory contribution in microseconds |
| Steering Travel | Scales driver steering only; it does not reduce gyro authority |
| Transition Speed | Correction-reversal timing; lower is slower and smoother, higher is faster and sharper |
| Driver Priority | Progressively reduces only fast direct gyro gain as steering moves away from center; `0` preserves full gyro response and `10-20` is the recommended first test range |
| Anti Wobble | Depth of the phase-aware dynamic 2.5-3.6 Hz wheel-wobble notch; `0` bypasses it, `50` is the recommended starting point, and `100` applies maximum depth |

Throttle prediction remains active when a valid throttle signal is present,
even with Prediction set to zero. The Prediction setting adds general
yaw-acceleration look-ahead; throttle temporarily extends that horizon before
the chassis response develops.

### Gyro filtering

The EdgeTX tool and web configurator expose three QMI8658 hardware modes:

- `24 Hz` (`gyro_lpf_mode=0`) is the original low-bandwidth response.
- `120 Hz` (`gyro_lpf_mode=1`) reduces phase delay while retaining hardware filtering.
- `Off` (`gyro_lpf_mode=2`) exposes the unfiltered sensor bandwidth.

`Smoothing 0.00` also bypasses the broad software filter. Change one filter at
a time and retune Gain after changing bandwidth. Anti Wobble remains useful
because it is a narrow wheel-mode notch rather than a broad yaw low-pass.

### Transition Speed

Transition Speed is tuned after the core settings. Start at `50`. Lower values
make gyro correction reverse more slowly for a calmer transition; higher values
move correction into the new direction more quickly for a sharper transition.
The response timing is independent of Gyro Gain and never changes the hard Max
Correction ceiling. The timing stage starts from driver transition intent,
stays active through the measured yaw reversal, and finishes smoothly before
the next settled drift. Test `25`, `50`, and `75` at the same tune first, then
refine the preferred direction.

### Driver Priority

Driver Priority is tuned after Gain and Transition Speed. At `0`, the existing
controller is unchanged. Increasing it progressively yields fast direct gyro
gain to the driver as the steering command moves away from center; a value of
`20` retains 80% of direct gain at full steering and 90% at half steering.
Countersteer Assist, Drift Memory, Max Correction, and physical endpoints are
not reduced. Start at `10`, then test `20`. Excessive priority can remove useful
stabilization near full countersteer, so the experimental range is capped at
`50`.

## Safe first test

Use a stand or hold the chassis with the wheels clear before driving.

| Setting | Initial value |
|---|---:|
| Gain | `1.50` |
| Deadband | `4` |
| Max Correction | `100%` |
| Smoothing | `0.01` |
| Countersteer Assist | `100` |
| Driver Priority | `0` |
| Prediction | `0` |
| Hold Assist | `0` |
| Drift Memory | `0.00` |
| Memory Limit | `80` |
| Servo Quiet | `0` |
| Control / servo rate | `250 Hz` |
| Transition Speed | `50` |
| Anti Wobble | `50` |

Check that rotating the chassis produces steering correction in the direction
that opposes the rotation. Reverse gyro correction if it assists the rotation.

Begin with low-speed entries:

1. Raise Gain until the car catches rotation decisively.
2. If the response is strong but runs out of steering, raise Max Correction in
   small steps.
3. If rapid chassis motion looks nervous, add Prediction in steps of `5`.
4. If the signal is visibly noisy, add Smoothing in steps of `0.01`. Do not use
   smoothing to repair a control oscillation.
5. If the car is stable but the driver carries too much of the settled countersteer, add Countersteer Assist in steps of `10`.
6. Once entries and transitions are clean, add Hold Assist in steps of `5`.
7. Add Drift Memory last in steps of `0.05`.

Change one setting at a time.

## Interpreting symptoms

| Symptom | First adjustment |
|---|---|
| Car does most of the work but gyro feels weak | Raise Gain |
| Initial response is strong but authority stops building | Raise Max Correction carefully |
| Fast response overshoots before settling | Add a small amount of Prediction |
| Prediction makes direction changes sharp or nervous | Lower Prediction |
| Transition happens too quickly or overshoots | Lower Transition Speed |
| Transition feels held back or rotates too slowly | Raise Transition Speed |
| Stable drift requires too much sustained driver countersteer | Raise Countersteer Assist |
| Gyro feels too hands-on after the drift settles | Lower Countersteer Assist |
| Long drift slowly wanders after entries are already good | Add Hold Assist |
| Quiet drift reference is present but does not correct enough | Add Drift Memory |
| Transition carries the old drift | Lower Hold Assist or Drift Memory |
| Mid-drift wheel oscillation | Lower Gain first and verify the servo and chassis; then raise Anti Wobble from its default `50` in steps of `10` |
| Correction sits at Max Correction | More gain will not add authority; inspect travel and geometry |

## Control and servo rate

Use **250 Hz** unless the servo documentation explicitly lists 333 Hz support. It is the compatibility setting and works with a broader range of digital servos. **333 Hz** shortens the command interval from 4 ms to about 3 ms and may improve response on a supported fast servo. Sending 333 Hz to an unsupported servo can cause buzzing, heat, erratic motion, or damage. Restart OpenDrift after changing the rate.

## Current v1.0 CSV fields

The `blackbox-v11.csv` logger records the current controller channels without
the retired alpha-era tuning fields:

| Field | Meaning |
|---|---|
| `gyro_requested_us` | Correction requested before Max Correction is applied |
| `gyro_limited_us` | Correction after the fixed Max Correction limit |
| `gyro_applied_us` | Correction actually available after combining gyro and driver steering |
| `correction_saturated` | `1` when either Max Correction or the final normalized steering range clipped the request |
| `predicted_yaw` | Filtered yaw plus short-horizon prediction |
| `drift_reference_yaw` | Learned quiet-drift yaw reference |
| `reference_error` | Filtered yaw minus drift reference |
| `reference_lock` | Continuous quiet-drift confidence |
| `throttle_prediction` | Active throttle load-change prediction blend |
| `direct_correction_us` | Gain-based direct correction |
| `driver_priority_pct` | Saved Driver Priority setting from 0–50 |
| `driver_priority_scale` | Smoothed multiplier currently applied to direct gyro gain; 1.0 is full gain |
| `effective_direct_gain` | Live base Gain after Driver Priority scaling |
| `countersteer_assist` | Saved Countersteer Assist setting from 0–100 |
| `countersteer_us` | Additional slow-reference countersteer contribution |
| `memory_feedback_us` | Drift Memory correction after its limit |
| `driver_activity_blend` | Driver steering-change activity |
| `steering_activity_us_s` | Filtered receiver steering rate |
| `transition_speed` | Saved correction-reversal speed from 0–100; start at `50` |
| `transition_speed_blend` | Signed configured speed while the transition timing stage is active; negative is slower and positive is faster |
| `transition_slew_us` | Actual gain-independent correction produced by the transition timing stage before Memory and Max Correction |
| `transition_authority_blend` | Detected driver/chassis transition envelope from 0 to 1 |
| `transition_prediction_scale` | Optional prediction multiplier; reduced while transitioning |
| `hunt_suppression` | Confidence-weighted attenuation applied to a confirmed periodic residual |
| `hunt_frequency_hz` | Detected settled-drift oscillation frequency |
| `hunt_residual_dps` | Fast yaw component around the slow sustained-drift baseline |
| `hunt_removed_us` | Correction removed from only that oscillating component |
| `hunt_consistent_half_cycles` | Number of consecutive frequency-consistent half-cycles observed |
| `hunt_latch` | Confirmed-event hold from 0 to 1; transitions clear it immediately |
| `anti_wobble` | Saved Anti Wobble notch-depth setting from 0-100; default `50` |

The stage-one onboard logger stores fixed-size binary records entirely in a
4 MB circular PSRAM buffer. It performs no internal-flash or filesystem writes
while driving. At the current 20 Hz sample rate, the complete telemetry set
retains approximately the newest 18 minutes of a run. Once full, the oldest
records are overwritten so the most recent behavior remains available.

Use **Download CSV** in the web configurator before removing power. CSV text is
generated from the binary records only during the download. The buffer is
volatile and is cleared by a power cycle or **Clear RAM Log**. A later SD-card
stage will continuously persist this same binary stream without returning to
internal FFat storage.

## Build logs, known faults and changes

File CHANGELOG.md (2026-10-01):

# Changelog

## Unreleased

### WiFi

- Units on the default network name now broadcast `OpenDrift-XXXX`, with a
  per-board suffix, so phones at a track with several cars no longer join the
  wrong one or switch between them. Custom names are unchanged.
- The access point scans channels 1, 6 and 11 when it starts and uses the
  quietest one, instead of always using channel 1.
- The access point is forced to a 20 MHz channel. That is half the spectrum
  of 40 MHz, so 2.4 GHz RC links that hop across the band clash with it less
  often.
- WiFi now waits at least 3 minutes for the first phone after it starts.
  Before, it turned off 40 s after power-on if nobody had connected yet.
- The AMOLED WiFi page, round display, boot log and web configurator show the
  network name actually being broadcast.

### Fixes

- A wobble around zero yaw (straight line, drift entry or exit) no longer
  counts as a direction change. The reversal trigger fired on every swing of
  the wobble, which kept the controller in the transition phase: Anti Wobble
  was held to a shallow 20 percent guard notch at any setting, prediction
  was cut and the transition slew added lag, so the wobble could not be
  damped. A reversal now only counts after the old direction was held for
  0.25 s, longer than any wheel-wobble half cycle; real drift transitions
  still arm it.

## v1.0.8 - 2026-09-03

### Lower-latency gyro experiments

- Adds selectable QMI8658 gyro-filter modes: the original `24 Hz`, a
  lower-latency `120 Hz` mode, and hardware LPF bypass for controlled testing.
- Makes Smoothing `0.00` a true software-filter bypass so hardware and software
  phase delay can be evaluated independently.
- Raises the supported gyro Gain ceiling from `3.00` to `6.00` while retaining
  the existing `0.50-3.00` Channel 3 mapping by default.

### Correction authority

- Refactors the controller to return a signed gyro correction instead of a
  centered pseudo-servo command, eliminating an unintended internal
  `1000-2000 us` saturation point.
- Redefines Max Correction across the full endpoint-to-endpoint steering span:
  `50%` can move from center to one endpoint, while `100%` can override one
  endpoint all the way to the other.
- Migrates existing Max Correction settings and saved profiles to preserve
  their real correction authority. An old displayed value of `74` becomes
  approximately `37` without weakening or doubling the tune.
- Stops Transition Speed from dynamically shrinking the Max Correction ceiling.
  It now shapes transition damping only.
- Keeps the combined driver-plus-gyro command and calibrated physical servo
  endpoints as the final hard safety limits.

### Channel 3 and EdgeTX

- Adds persistent `CH3 Gain Min` and `CH3 Gain Max` controls to the EdgeTX Lua
  tool and onboard web configurator, adjustable from `0.00` to `6.00`.
- Keeps Channel 3 authoritative while its receiver signal is valid and reports
  the resulting live gain consistently to the display and EdgeTX tool.
- Adds the gyro LPF selector and expanded `0.00-6.00` Active Gain range to the
  current `OpenDrift.lua` release asset.

### Blackbox and documentation

- Adds `gyro_lpf_mode` so matched filter tests identify the active sensor mode.
- Replaces ambiguous correction columns with `gyro_requested_us`,
  `gyro_limited_us`, and `gyro_applied_us`.
- Adds `correction_saturated` to distinguish Max Correction clipping from final
  steering-range saturation during entries and transitions.
- Updates the tuning reference and website for the new gain range, filter modes,
  full-span Max Correction behavior, tune migration, and test procedure.

### Release targets

- Publishes Waveshare AMOLED 1.64 V1 and V2 firmware with PWM and CRSF receiver
  support.
- The deprecated Waveshare Round 1.28 builds remain available at v1.0.7c and
  are not part of the v1.0.8 public release.

## v1.0.7c - 2026-08-30

### Physical steering limits

- Replaces receiver-range calibration with physical servo endpoint calibration.
- Captures the servo's actual left, center, and right PWM positions and uses
  them as the final asymmetric output map and hard safety clamp.
- Invalidates v1.0.7b receiver-range captures because they are not safe to
  reinterpret as physical servo limits.
- Redefines Max Correction as `0-100%` of calibrated physical steering travel;
  existing settings and profiles migrate from the previous +/-500 us scale.
- Makes Steering Travel affect driver input only, leaving gyro authority to
  Max Correction and the calibrated physical endpoints.
- Gives both AMOLED and round displays dedicated red/green physical endpoint
  pages and keeps the same captures synchronized with the EdgeTX tool.

## v1.0.7b - 2026-08-29

### Steering calibration

- Moves AMOLED steering calibration onto its own page with three large capture targets.
- Gives each endpoint a red-to-green confirmation state and reports missing signal or invalid endpoint ordering directly on screen.
- Fixes stale touch hitboxes that could interpret endpoint taps as swipe gestures.
- Normalizes captured left/right PWM values so reversed transmitter channels calibrate correctly.
- Persists shared left/center/right capture state and synchronizes calibration status between the AMOLED page, web configurator, CRSF device, and EdgeTX tool.
- Adds `Capture Left`, `Capture Center`, and `Capture Right` actions to `OpenDrift.lua` with an always-visible calibration status.

## v1.0.7 - 2026-08-27

### Control

- Replaces event-gated hunt damping with a narrow phase-aware dynamic notch targeting the measured 2.5-3.6 Hz wheel-wobble mode.
- Keeps a shallow guard active through entries and transitions, then blends smoothly to full settled-drift depth.
- Tracks notch center frequency only during suitable settled conditions so deliberate chassis motion does not retune the filter.
- Improves transition prediction and damping through the complete yaw reversal.
- Renames the user-facing **Hunt Strength** control to **Anti Wobble** and keeps its fresh-install default at `50`.
- Preserves existing saved tunes by retaining the compatible preference and profile storage layout.

### Reliability and interface

- Defers CRSF UART startup until the AMOLED, IMU, UI, and shared resources are ready.
- Adds a deliberate AMOLED hardware-reset sequence and startup settling delay for more reliable power-up and rapid power-cycle recovery.
- Makes WiFi auto-off count from the most recent client disconnect instead of initial startup.
- Enlarges the AMOLED steering endpoint buttons for easier trackside calibration.

### Blackbox and documentation

- Adds dynamic-notch residual, removed correction, envelope, latch, consistent-cycle, and tracked-frequency telemetry.
- Renames the saved blackbox control column from `hunt_strength` to `anti_wobble`.
- Updates the technical guide, web tuning guide, web configurator help, CRSF documentation, and EdgeTX tool for Anti Wobble and current Transition Speed behavior.

### Hardware

- Corrects the OpenDrift daughterboard regulator enable/feedback connections and updates the PCB routing to match the repaired schematic.
- Waveshare AMOLED 1.64 V1 and V2 PWM/CRSF builds are included.
- The deprecated Waveshare Round 1.28 firmware remains frozen at v1.0.2.

## v1.0.6 - 2026-08-17

- Added selectable 250/333 Hz control and steering-servo output.
- Improved transition authority and off-throttle prediction.
- Added the first bounded settled-drift hunt-suppression implementation and supporting blackbox telemetry.

## v1.0.5 - 2026-08-14

- Replaced internal-flash blackbox writes with non-blocking PSRAM circular logging.

## v1.0.4 - 2026-08-12

- Synchronized live channel-3 gain across the display, web configurator, CRSF telemetry, and EdgeTX tool.

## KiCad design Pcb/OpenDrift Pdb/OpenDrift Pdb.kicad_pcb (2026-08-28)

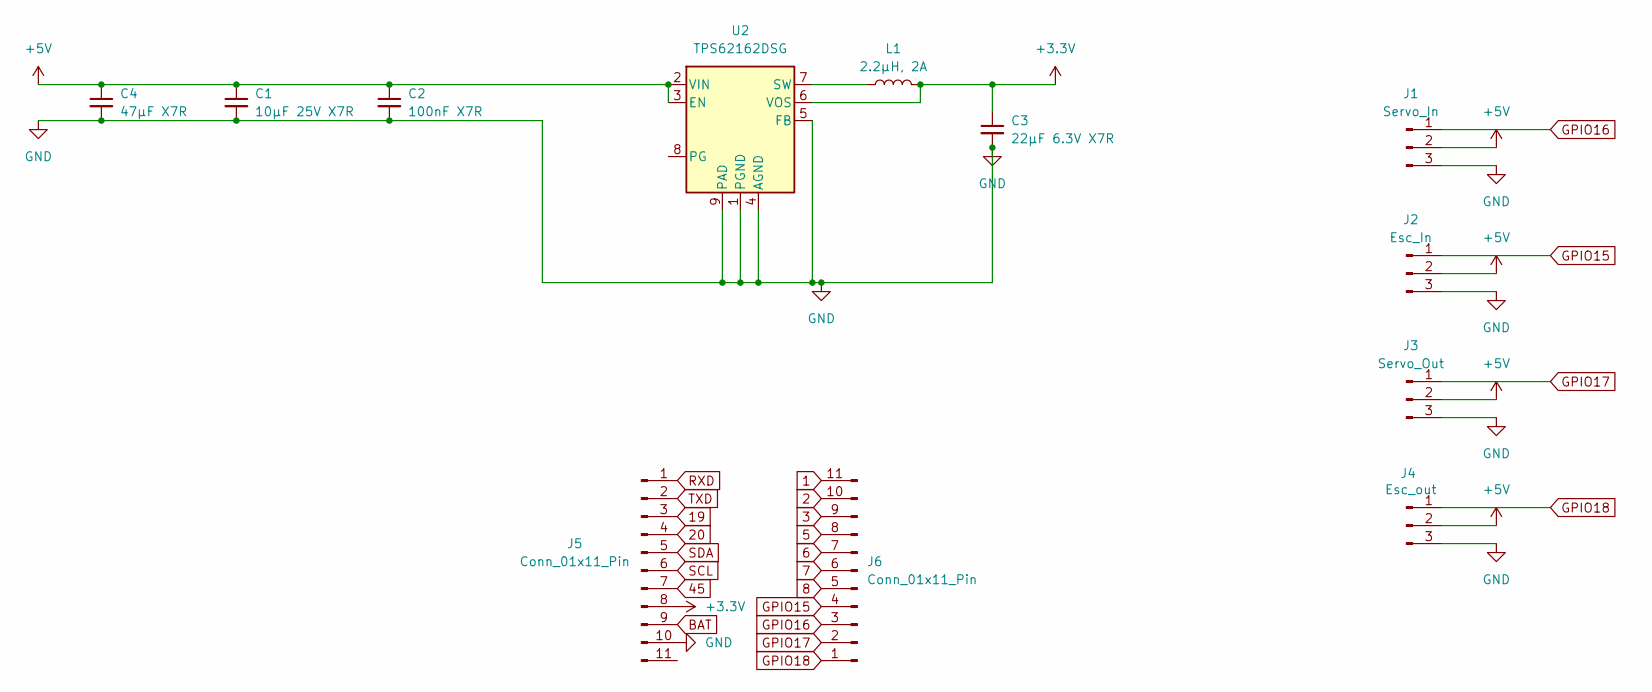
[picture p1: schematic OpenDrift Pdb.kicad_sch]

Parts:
C1: 10µF 25V X7R; C_0805_2012Metric
C2: 100nF X7R; C_0603_1608Metric
C3: 22µF 6.3V X7R; C_0805_2012Metric
C4: 47µF X7R; C_0805_2012Metric
J1: Servo_In; JST_PH_S3B-PH-K_1x03_P2.00mm_Horizontal
J2: Esc_In; JST_PH_S3B-PH-K_1x03_P2.00mm_Horizontal
J3: Servo_Out; JST_PH_S3B-PH-K_1x03_P2.00mm_Horizontal
J4: Esc_out; JST_PH_S3B-PH-K_1x03_P2.00mm_Horizontal
J5, J6: Conn_01x11_Pin; PinHeader_1x11_P2.54mm_Vertical
L1: 2.2µH, 2A; L_Coilcraft_XAL4020-XXX
U2: TPS62162DSG; WSON-8-1EP_2x2mm_P0.5mm_EP0.9x1.6mm_ThermalVias

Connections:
1: J6.11
2: J6.10
3: J6.9
5: J6.8
6: J6.7
7: J6.6
8: J6.5
19: J5.3
20: J5.4
45: J5.7
+3.3V: C3.1, J5.8, L1.2, U2.6 (VOS)
+5V: C1.1, C2.1, C4.1, J1.2, J2.2, J3.2, J4.2, U2.2 (VIN), U2.3 (EN)
BAT: J5.9
GND: C1.2, C2.2, C3.2, C4.2, J1.3, J2.3, J3.3, J4.3, J5.10, U2.1 (PGND), U2.4 (AGND), U2.5 (FB), U2.9 (PAD)
GPIO15: J2.1, J6.4
GPIO16: J1.1, J6.3
GPIO17: J3.1, J6.2
GPIO18: J4.1, J6.1
unnamed: L1.1, U2.7 (SW)
RXD: J5.1
SCL: J5.6
SDA: J5.5
TXD: J5.2

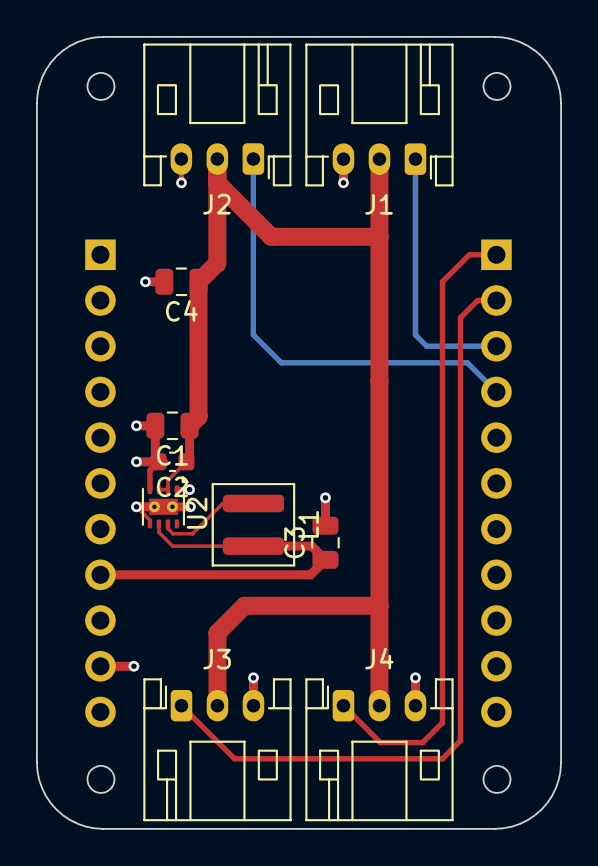
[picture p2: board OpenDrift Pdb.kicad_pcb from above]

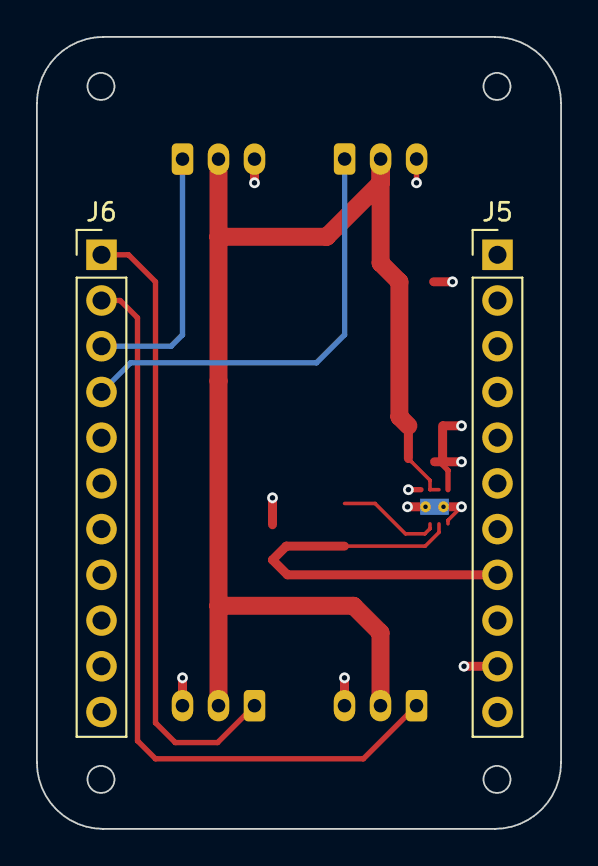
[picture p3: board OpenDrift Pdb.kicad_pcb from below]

Board: 4 copper layers, 29.1 x 44.0 mm, 12 parts (2 on the bottom side), 8 nets.

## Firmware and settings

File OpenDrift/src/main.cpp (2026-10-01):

#include <Arduino.h>
#include <WiFi.h>
#include <freertos/FreeRTOS.h>
#include <freertos/semphr.h>
#include <freertos/task.h>
#include <esp_system.h>

#if !defined(OPENDRIFT_HEADLESS)
#include "LGFX_OpenDrift.hpp"
#include "Touch.h"
#include "UI.h"
#endif
#if defined(OPENDRIFT_BOARD_MATRIX)
#include "MatrixStatus.h"
#endif
#include "IMU.h"
#include "Servo.h"
#include "EscOutput.h"
#include "GyroController.h"
#include "WIFIManager.h"
#include "Settings.h"
#include "RadioInput.h"
#if defined(OPENDRIFT_INPUT_CRSF)
#include "CrsfInput.h"
#include "CrsfParameterDevice.h"
#if defined(OPENDRIFT_BOARD_AMOLED_164)
#include "AuxChannelOutputs.h"
#endif
#endif
#include "WebConfigurator.h"
#include "BlackboxLogger.h"
#if defined(OPENDRIFT_BOARD_AMOLED_164)
#include "Backgrounds.h"
#endif

#if !defined(OPENDRIFT_HEADLESS)
LGFX lcd;
#endif

IMU imu;

ServoOutput steeringServo;

EscOutput throttleOutput;

GyroController gyro;

#if !defined(OPENDRIFT_HEADLESS)
Touch touch;
UI ui;
#endif

#if defined(OPENDRIFT_BOARD_MATRIX)
MatrixStatus matrixStatus;
#endif

WiFiManager wifi;

Settings settings;

WebConfigurator webConfig;

RadioInput steeringRadio;

RadioInput gainRadio;

RadioInput throttleRadio;

#if defined(OPENDRIFT_INPUT_CRSF)
CrsfInput crsf;
CrsfParameterDevice crsfParameters;
#if defined(OPENDRIFT_BOARD_AMOLED_164)
AuxChannelOutputs auxChannelOutputs;
#endif
#endif

BlackboxLogger blackbox;

#if defined(OPENDRIFT_BOARD_AMOLED_164)
Backgrounds backgrounds;
#endif

unsigned long lastBlackboxLog = 0;

bool blackboxStarted = false;

bool lastBlackboxEnabled = false;

bool blackboxStartAttempted = false;

static uint32_t controlLoopHz = 250;
static uint32_t controlLoopPeriodMs = 4;
static uint8_t appliedDisplayRotation = 0xFF;

#if defined(OPENDRIFT_BOARD_AMOLED_164)
static constexpr uint8_t STARTUP_RETRY_COUNT = 3;
static constexpr int I2C_SDA_PIN = 47;
static constexpr int I2C_SCL_PIN = 48;
static constexpr int AMOLED_RESET_PIN = 21;
#if defined(OPENDRIFT_AMOLED_V2)
static constexpr int AMOLED_CS_PIN = 46;
#else
static constexpr int AMOLED_CS_PIN = 9;
#endif
#endif

struct ControlTelemetry
{
    float yaw = 0.0f;
    int requestedGyroCorrection = 0;
    int limitedGyroCorrection = 0;
    int appliedGyroCorrection = 0;
    bool correctionSaturated = false;
    int steeringCommand = 1500;
    int servoCommand = 1500;
    bool steeringSignal = false;
    bool throttleSignal = false;
    bool imuHealthy = true;
};

ControlTelemetry controlTelemetry;

portMUX_TYPE controlTelemetryMux =
    portMUX_INITIALIZER_UNLOCKED;

SemaphoreHandle_t i2cBusMutex = nullptr;

TaskHandle_t controlTaskHandle = nullptr;

#if defined(OPENDRIFT_INPUT_CRSF)
TaskHandle_t crsfTaskHandle = nullptr;
#endif

#if defined(OPENDRIFT_INPUT_CRSF)
#if defined(OPENDRIFT_CRSF_OOPS_SWAPPED_PINS)
#define SERVO_OUTPUT_PIN 16
#define CRSF_RX_PIN 17
#define CRSF_TX_PIN 18
#define CRSF_THROTTLE_OUTPUT_PIN 15
#elif defined(OPENDRIFT_BOARD_MATRIX)
#define SERVO_OUTPUT_PIN 1
#define CRSF_RX_PIN 3
#define CRSF_TX_PIN 4
#define CRSF_THROTTLE_OUTPUT_PIN 2
#elif defined(OPENDRIFT_AMOLED_V2)
// V2 connects the IMU and touch interrupt outputs to GPIO17/18. Keep the
// receiver UART off those lines to prevent electrical contention.
#define SERVO_OUTPUT_PIN 15
#define CRSF_RX_PIN 1
#define CRSF_TX_PIN 2
#define CRSF_THROTTLE_OUTPUT_PIN 16
#else
#define SERVO_OUTPUT_PIN 15
#define CRSF_RX_PIN 17
#define CRSF_TX_PIN 18
#define CRSF_THROTTLE_OUTPUT_PIN 16
#endif
static constexpr uint8_t CRSF_STEERING_CHANNEL = 0;
static constexpr uint8_t CRSF_THROTTLE_CHANNEL = 1;
static constexpr uint8_t CRSF_GAIN_CHANNEL = 2;
static constexpr uint32_t CRSF_SIGNAL_TIMEOUT_MS = 50;
static constexpr uint32_t CRSF_THROTTLE_NEUTRAL_MS = 500;
static constexpr int CRSF_THROTTLE_NEUTRAL_BAND_US = 50;
#else
#if defined(OPENDRIFT_BOARD_MATRIX)
#define SERVO_OUTPUT_PIN 3
#define RADIO_STEERING_PIN 1
#define RADIO_THROTTLE_PIN 2
#elif defined(OPENDRIFT_AMOLED_V2)
#define SERVO_OUTPUT_PIN 1
#define RADIO_STEERING_PIN 15
#define RADIO_THROTTLE_PIN 16
#else
#define SERVO_OUTPUT_PIN 17
#define RADIO_STEERING_PIN 15
#define RADIO_THROTTLE_PIN 16
#endif
#endif
#if defined(OPENDRIFT_BOARD_MATRIX)
#define SHARED_GAIN_THROTTLE_PIN 4
#elif defined(OPENDRIFT_AMOLED_V2)
#define SHARED_GAIN_THROTTLE_PIN 2
#else
#define SHARED_GAIN_THROTTLE_PIN 18
#endif

bool pin18ModeConfigured = false;

volatile bool pin18ThrottleOutputMode = false;

volatile bool throttleOutputActive = false;

#if defined(OPENDRIFT_INPUT_CRSF)
volatile bool crsfThrottleArmed = false;
bool lastCrsfSignal = false;
volatile uint32_t crsfThrottleNeutralSinceMs = 0;
volatile bool crsfThrottleSignalSnapshot = false;
volatile float crsfThrottlePulseSnapshot = 1500.0f;
volatile bool crsfThrottleOutputArmed = false;
#endif

volatile bool gyroCalibrationRequested = false;


void requestGyroCalibration()
{
    gyroCalibrationRequested = true;
}

const char* password = "opendrift";


#if defined(OPENDRIFT_BOARD_AMOLED_164)
static constexpr float AMOLED_BOOT_LOG_TEXT_SIZE = 1.15f;
#endif

#if defined(OPENDRIFT_HEADLESS)
static constexpr uint16_t TFT_RED = 0;
static constexpr uint16_t TFT_GREEN = 0;
static constexpr uint16_t TFT_YELLOW = 0;
static constexpr uint16_t TFT_CYAN = 0;
#endif


const char* resetReasonName(
    esp_reset_reason_t reason
)
{
    switch(reason)
    {
        case ESP_RST_POWERON: return "power-on";
        case ESP_RST_EXT: return "external-reset";
        case ESP_RST_SW: return "software-reset";
        case ESP_RST_PANIC: return "panic";
        case ESP_RST_INT_WDT: return "interrupt-watchdog";
        case ESP_RST_TASK_WDT: return "task-watchdog";
        case ESP_RST_WDT: return "watchdog";
        case ESP_RST_DEEPSLEEP: return "deep-sleep";
        case ESP_RST_BROWNOUT: return "brownout";
        case ESP_RST_SDIO: return "sdio";
        #if defined(ESP_RST_USB)
        case ESP_RST_USB: return "usb";
        #endif
        #if defined(ESP_RST_JTAG)
        case ESP_RST_JTAG: return "jtag";
        #endif
        #if defined(ESP_RST_PWR_GLITCH)
        case ESP_RST_PWR_GLITCH: return "power-glitch";
        #endif
        #if defined(ESP_RST_CPU_LOCKUP)
        case ESP_RST_CPU_LOCKUP: return "cpu-lockup";
        #endif
        default: return "unknown";
    }
}


#if defined(OPENDRIFT_BOARD_AMOLED_164)
void releaseI2cBus()
{
    Wire.end();

    pinMode(I2C_SDA_PIN, INPUT_PULLUP);
    pinMode(I2C_SCL_PIN, OUTPUT_OPEN_DRAIN);
    digitalWrite(I2C_SCL_PIN, HIGH);
    delayMicroseconds(10);

    // A peripheral interrupted mid-byte can hold SDA low indefinitely.
    // Nine clocks finish that byte before generating a STOP condition.
    for(uint8_t pulse = 0; pulse < 9; pulse++)
    {
        digitalWrite(I2C_SCL_PIN, LOW);
        delayMicroseconds(10);
        digitalWrite(I2C_SCL_PIN, HIGH);
        delayMicroseconds(10);
    }

    pinMode(I2C_SDA_PIN, OUTPUT_OPEN_DRAIN);
    digitalWrite(I2C_SDA_PIN, LOW);
    delayMicroseconds(10);
    digitalWrite(I2C_SCL_PIN, HIGH);
    delayMicroseconds(10);
    digitalWrite(I2C_SDA_PIN, HIGH);
    delayMicroseconds(10);

    pinMode(I2C_SDA_PIN, INPUT_PULLUP);
    pinMode(I2C_SCL_PIN, INPUT_PULLUP);
}


void resetAmoledPanelHardware()
{
    // Hold chip-select inactive while the panel reset line is sequenced. This
    // prevents partial QSPI commands if the ESP starts before the AMOLED rail
    // has completely settled or after a short off/on power cycle.
    pinMode(AMOLED_CS_PIN, OUTPUT);
    digitalWrite(AMOLED_CS_PIN, HIGH);

    pinMode(AMOLED_RESET_PIN, OUTPUT);
    digitalWrite(AMOLED_RESET_PIN, HIGH);
    delay(10);
    digitalWrite(AMOLED_RESET_PIN, LOW);
    delay(20);
    digitalWrite(AMOLED_RESET_PIN, HIGH);
    delay(120);
}
#endif


void applyDisplayRotation()
{
    uint8_t rotation = settings.getDisplayRotation();

    if(rotation == appliedDisplayRotation)
    {
        return;
    }

    #if defined(OPENDRIFT_BOARD_MATRIX)
    matrixStatus.setRotation(rotation);
    #elif defined(OPENDRIFT_BOARD_AMOLED_164)
    lcd.setRotation(rotation);
    touch.setRotation(rotation);
    ui.requestRefresh();
    #endif

    appliedDisplayRotation = rotation;

    Serial.printf(
        "Display rotation: %u degrees\n",
        (unsigned int)rotation * 90
    );
}



#if !defined(OPENDRIFT_HEADLESS)
class BootConsole
{

public:

    void begin(
        LGFX* display
    )
    {
        #if defined(OPENDRIFT_BOARD_AMOLED_164)
        this->display = display;

        bool usePsram =
            psramFound();

        canvas.setPsram(
            usePsram
        );

        panelCanvas.setPsram(
            usePsram
        );

        canvas.setColorDepth(16);
        panelCanvas.setColorDepth(16);

        canvasReady =
            canvas.createSprite(456, 280) != nullptr;

        panelReady =
            panelCanvas.createSprite(280, 456) != nullptr;

        if(!canvasReady || !panelReady)
        {
            return;
        }

        canvas.fillScreen(TFT_BLACK);
        canvas.setTextWrap(false);
        canvas.setTextColor(TFT_WHITE);
        canvas.setTextSize(2);
        canvas.drawString(
            #if defined(OPENDRIFT_INPUT_CRSF)
            #if defined(OPENDRIFT_CRSF_OOPS_SWAPPED_PINS)
            "OpenDrift PERSONAL OOPS boot",
            #else
            "OpenDrift CRSF verbose boot",
            #endif
            #else
            "OpenDrift verbose boot",
            #endif
            8,
            7
        );

        canvas.setTextSize(AMOLED_BOOT_LOG_TEXT_SIZE);
        canvas.setTextColor(0x7BEF);
        canvas.drawString(
            #if defined(OPENDRIFT_INPUT_CRSF)
            #if defined(OPENDRIFT_CRSF_OOPS_SWAPPED_PINS)
            "WARNING swapped pins: 15E 16S 17T 18R",
            #else
            "control kernel 1.0.9 crsf ttyOD0",
            #endif
            #else
            "control kernel 1.0.9 pwm  ttyOD0",
            #endif
            8,
            27
        );

        nextLineY = 44;
        flush();
        #else
        this->display = display;

        display->fillScreen(TFT_BLACK);
        display->setTextWrap(false);
        display->setTextColor(TFT_WHITE);
        display->setTextSize(2);
        display->drawCenterString(
            #if defined(OPENDRIFT_INPUT_CRSF)
            "OpenDrift CRSF BETA",
            #else
            "OpenDrift OPEN BETA",
            #endif
            120,
            12
        );

        display->setTextSize(1);
        display->setTextColor(0x7BEF);
        display->drawCenterString(
            "control kernel 2.0-round  ttyOD0",
            120,
            32
        );

        nextLineY = 49;
        #endif
    }


    void log(
        const char* message,
        const char* status = "[ OK ]",
        uint16_t statusColor = TFT_GREEN
    )
    {
        Serial.print(status);
        Serial.print(" ");
        Serial.println(message);

        #if defined(OPENDRIFT_BOARD_AMOLED_164)
        if(!canvasReady || !panelReady)
        {
            return;
        }

        if(nextLineY > 263)
        {
            canvas.fillScreen(TFT_BLACK);
            canvas.setTextSize(AMOLED_BOOT_LOG_TEXT_SIZE);
            canvas.setTextColor(0x7BEF);
            canvas.drawString(
                "OpenDrift boot log (continued)",
                8,
                8
            );
            nextLineY = 27;
        }

        char timestamp[16];

        snprintf(
            timestamp,
            sizeof(timestamp),
            "[%7.3f]",
            millis() / 1000.0f
        );

        canvas.setTextSize(AMOLED_BOOT_LOG_TEXT_SIZE);
        canvas.setTextColor(0x8410);
        canvas.drawString(timestamp, 8, nextLineY);

        canvas.setTextColor(statusColor);
        canvas.drawString(status, 76, nextLineY);

        canvas.setTextColor(TFT_WHITE);
        canvas.drawString(message, 120, nextLineY);

        nextLineY += 13;
        flush();
        #else
        if(display == nullptr)
        {
            return;
        }

        if(nextLineY > 211)
        {
            display->fillScreen(TFT_BLACK);
            display->setTextSize(1);
            display->setTextColor(0x7BEF);
            display->drawCenterString(
                "OpenDrift boot log (continued)",
                120,
                18
            );
            nextLineY = 42;
        }

        char timestamp[12];

        snprintf(
            timestamp,
            sizeof(timestamp),
            "[%5.2f]",
            millis() / 1000.0f
        );

        display->setTextSize(1);
        display->setTextColor(0x8410);
        display->drawString(timestamp, 7, nextLineY);

        display->setTextColor(statusColor);
        display->drawString(status, 58, nextLineY);

        display->setTextColor(TFT_WHITE);
        display->drawString(message, 99, nextLineY);

        nextLineY += 12;
        #endif
    }


    void end()
    {
        #if defined(OPENDRIFT_BOARD_AMOLED_164)
        canvas.deleteSprite();
        panelCanvas.deleteSprite();
        canvasReady = false;
        panelReady = false;
        display = nullptr;
        #else
        display = nullptr;
        #endif
    }


private:

    LGFX* display = nullptr;
    int nextLineY = 43;

    #if defined(OPENDRIFT_BOARD_AMOLED_164)
    LGFX_Sprite canvas;
    LGFX_Sprite panelCanvas;
    bool canvasReady = false;
    bool panelReady = false;


    void flush()
    {
        if(display == nullptr)
        {
            return;
        }

        uint16_t* source =
            static_cast<uint16_t*>(
                canvas.getBuffer()
            );

        uint16_t* target =
            static_cast<uint16_t*>(
                panelCanvas.getBuffer()
            );

        for(int y = 0; y < 280; y++)
        {
            for(int x = 0; x < 456; x++)
            {
                target[
                    ((455 - x) * 280) + y
                ] = source[(y * 456) + x];
            }
        }

        panelCanvas.pushSprite(
            display,
            0,
            0
        );
    }
    #endif
};
#else
class BootConsole
{
public:
    void begin()
    {
    }

    void log(
        const char* message,
        const char* status = "[ OK ]",
        uint16_t statusColor = 0
    )
    {
        (void)statusColor;
        Serial.print(status);
        Serial.print(" ");
        Serial.println(message);
    }

    void end()
    {
    }
};
#endif


BootConsole bootConsole;
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
void loop()
{
    static unsigned long lastHeartbeatMs = 0;

    #if defined(OPENDRIFT_INPUT_CRSF)
    crsfParameters.update();

    if(crsfParameters.consumeSettingsChanged())
    {
        #if !defined(OPENDRIFT_HEADLESS)
        ui.requestRefresh();
        #endif
    }
    #endif

    if(millis() - lastHeartbeatMs > 5000)
    {
        lastHeartbeatMs =
            millis();

        Serial.println("OpenDrift heartbeat");

        #if defined(OPENDRIFT_INPUT_CRSF)
        Serial.printf(
            "CRSF bytes=%lu frames=%lu channels=%lu crc=%lu age=%lu ms LQ=%u SNR=%d throttle=%s\n",
            (unsigned long)crsf.getReceivedByteCount(),
            (unsigned long)crsf.getValidFrameCount(),
            (unsigned long)crsf.getChannelFrameCount(),
            (unsigned long)crsf.getCrcErrorCount(),
            (unsigned long)crsf.getFrameAgeMs(),
            crsf.getUplinkLinkQuality(),
            crsf.getUplinkSnr(),
            (crsfThrottleArmed && crsfThrottleOutputArmed)
            ? "ARMED"
            : "LOCKED"
        );
        #endif
    }

    #if !defined(OPENDRIFT_HEADLESS)
    if(i2cBusMutex != nullptr)
    {
        xSemaphoreTake(
            i2cBusMutex,
            portMAX_DELAY
        );
    }

    touch.update();

    if(i2cBusMutex != nullptr)
    {
        xSemaphoreGive(
            i2cBusMutex
        );
    }
    #endif

    //-------------------
    // SETTINGS
    //-------------------

    settings.update();

    updateBlackboxAvailability();

    //-------------------
    // WIFI
    //-------------------

    wifi.update();

    wifi.setTimeout(
        settings.getWifiTimeout()
    );

    if(
        wifi.isEnabled() &&
        !webConfig.isRunning()
    )
    {
        webConfig.begin(
            settings,
            gyro,
            steeringRadio,
            gainRadio,
            throttleRadio,
            blackbox
        );
    }

    if(wifi.isEnabled())
    {
        webConfig.update();
    }

    // Web and CRSF writes become visible immediately. AMOLED touch uses the
    // same rotation so its hit targets continue to follow the rendered UI.
    applyDisplayRotation();

    configurePin18Mode();

    #if defined(OPENDRIFT_INPUT_CRSF)
    bool crsfThrottleSignal =
        crsfThrottleSignalSnapshot;

    float crsfThrottlePulse =
        crsfThrottlePulseSnapshot;

    updateCrsfThrottleOutput(
        crsfThrottlePulse,
        crsfThrottleSignal
    );

    #if defined(OPENDRIFT_BOARD_AMOLED_164)
    auxChannelOutputs.update(
        settings,
        crsf,
        crsf.hasSignal(CRSF_SIGNAL_TIMEOUT_MS)
    );
    #endif
    #else
    if(
        pin18ThrottleOutputMode &&
        throttleRadio.hasSignal()
    )
    {
        if(!throttleOutputActive)
        {
            throttleOutput.configure(
                1500,
                false,
                100,
                0
            );

            throttleOutputActive =
                throttleOutput.begin(
                    SHARED_GAIN_THROTTLE_PIN,
                    settings.getThrottleOutputHz()
                );
        }

    }
    else if(
        pin18ThrottleOutputMode &&
        throttleOutputActive
    )
    {
        // Removing the PWM signal lets the ESC's own signal-loss
        // failsafe take over instead of holding the last throttle value.
        throttleOutput.end();
        throttleOutputActive = false;

        pinMode(
            SHARED_GAIN_THROTTLE_PIN,
            INPUT_PULLDOWN
        );
    }
    #endif

    #if !defined(OPENDRIFT_HEADLESS)
    //-------------------
    // UI
    //-------------------

    ui.update(
        touch,
        gyro,
        imu,
        wifi,
        settings,
        steeringRadio,
        gainRadio
    );
    #endif

    ControlTelemetry telemetry;

    portENTER_CRITICAL(
        &controlTelemetryMux
    );

    telemetry =
        controlTelemetry;

    portEXIT_CRITICAL(
        &controlTelemetryMux
    );

    #if defined(OPENDRIFT_BOARD_MATRIX)
    matrixStatus.update(
        telemetry.steeringSignal,
        wifi.isEnabled(),
        settings.getBlackboxEnabled() && blackbox.isReady()
    );
    #endif

    //-------------------
    // BLACKBOX LOG
    //-------------------

    if(
        settings.getBlackboxEnabled() &&
        blackbox.isReady() &&
        telemetry.steeringSignal &&
        millis() - lastBlackboxLog >= 50
    )
    {
        lastBlackboxLog =
            millis();

        blackbox.log(
            lastBlackboxLog,
            telemetry.yaw,
            gyro.getFilteredYaw(),
            imu.getGyroX(),
            imu.getGyroY(),
            imu.getAccelX(),
            imu.getAccelY(),
            imu.getAccelZ(),
            imu.getAccelMagnitude(),
            imu.getAccelDelta(),
            imu.getTiltRate(),
            imu.getSurfaceDisturbanceScore(),
            telemetry.requestedGyroCorrection,
            telemetry.limitedGyroCorrection,
            telemetry.appliedGyroCorrection,
            telemetry.correctionSaturated,
            steeringRadio.getPulseWidth(),
            telemetry.steeringCommand,
            telemetry.servoCommand,
            settings.getServoQuiet(),
            throttleRadio.getPulseWidth(),
            gainRadio.getPulseWidth(),
            gyro.getGain(),
            settings.getDriverPriority(),
            gyro.getDriverPriorityScale(),
            gyro.getEffectiveDirectGain(),
            settings.getDeadband(),
            settings.getGyroMaxCorrection(),
            settings.getGyroSmoothing(),
            imu.getGyroLpfMode(),
            settings.getGyroIntegralGain(),
            settings.getGyroIntegralLimit(),
            gyro.getIntegralCorrection(),
            settings.getGyroHoldBoost(),
            settings.getGyroCounterSteerAssist(),
            settings.getPredictionStrength(),
            gyro.getPredictedYaw(),
            gyro.getDriftReferenceYaw(),
            gyro.getReferenceError(),
            gyro.getReferenceLock(),
            gyro.getThrottlePrediction(),
            gyro.getDirectCorrection(),
            gyro.getCounterSteerCorrection(),
            gyro.getMemoryFeedback(),
            gyro.getDriverActivityBlend(),
            gyro.getThrottlePredictionBlend(),
            gyro.getSteeringActivity(),
            gyro.getControlPhase(),
            gyro.getSettledBlend(),
            gyro.getThrottleTransient(),
            telemetry.steeringSignal,
            telemetry.throttleSignal,
            gainRadio.hasSignal(),
            pin18ThrottleOutputMode,
            settings.getGyroTransitionSpeed(),
            gyro.getTransitionSpeedBlend(),
            gyro.getTransitionSlewCorrection(),
            gyro.getHuntSuppression(),
            gyro.getHuntFrequency(),
            gyro.getTransitionAuthorityBlend(),
            gyro.getThrottleLiftBlend(),
            gyro.getTransitionPredictionScale(),
            gyro.getHuntResidual(),
            gyro.getHuntRemovedCorrection(),
            gyro.getHuntConsistentHalfCycles(),
            gyro.getHuntLatch(),
            settings.getGyroHuntStrength(),
            gyro.getHuntResidualEnvelope(),
            gyro.getHuntNotchCenter()
        );
    }

    delay(1);
}
 

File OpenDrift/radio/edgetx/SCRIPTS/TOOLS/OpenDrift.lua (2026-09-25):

-- OpenDrift CRSF tuning tool for EdgeTX monochrome radios (including MT12).

local DEVICE = 0xC8
local RADIO = 0xEA

local fields = {
  { 1, "Saved Gain",       0,  600,   5, 2 },
  {37, "Live Gain",        0,  600,   5, 2, false, false, false, false, false, false, false, false, true},
  {33, "CH3 Gain Min",     0,  600,   5, 2 },
  {34, "CH3 Gain Max",     0,  600,   5, 2 },
  { 2, "Deadband",         0, 1000,   1, 1 },
  { 3, "Max Corr %",       0,  100,   1, 0 },
  { 4, "Smoothing",        0,  100,   1, 2 },
  {32, "Gyro LPF",         0,    2,   1, 0, true, false, false, false, false, true},
  { 5, "Drift Memory",     0, 2000,   1, 2 },
  { 6, "Memory Limit",     0,  500,   5, 0 },
  { 7, "Hold Assist",      0,  100,   1, 0 },
  { 8, "Countersteer",     0,  100,   1, 0 },
  { 9, "Transition Speed", 0,  100,   1, 0 },
  {38, "Driver Priority",  0,   50,   1, 0 },
  {10, "Prediction",       0,  100,   1, 0 },
  {26, "Anti Wobble",      0,  100,   1, 0 },
  {36, "Wobble Scale",     0,    1,   1, 0, true, false, false, false, false, false, false, true},
  {11, "Servo Quiet",      0,   50,   1, 0 },
  {12, "Steering Travel",  0,  100,   1, 0 },
  {27, "Endpoints",        0,    2,   1, 0, true, false, false, true, false},
  {28, "Capture Left",     0,    1,   1, 0, true, false, false, false, true},
  {29, "Capture Center",   0,    1,   1, 0, true, false, false, false, true},
  {30, "Capture Right",    0,    1,   1, 0, true, false, false, false, true},
  {31, "Reset Cal",        0,    1,   1, 0, true, false, false, false, true},
  {13, "Servo Travel",     1,  100,   1, 0 },
  {14, "Servo Center",  1000, 2000,   1, 0 },
  {15, "Servo Reverse",    0,    1,   1, 0, true},
  {16, "Gyro Reverse",     0,    1,   1, 0, true},
  {17, "GPIO 1 Output",    0,   16,   1, 0, true, true},
  {18, "GPIO 2 Output",    0,   16,   1, 0, true, true},
  {19, "GPIO 3 Output",    0,   16,   1, 0, true, true},
  {20, "GPIO 4 Output",    0,   16,   1, 0, true, true},
  {21, "GPIO 5 Output",    0,   16,   1, 0, true, true},
  {22, "GPIO 6 Output",    0,   16,   1, 0, true, true},
  {23, "GPIO 7 Output",    0,   16,   1, 0, true, true},
  {24, "GPIO 8 Output",    0,   16,   1, 0, true, true},
  {25, "Servo Rate*",      0,    1,   1, 0, true, false, true},
  {39, "Throttle Rate*",   0,    2,   1, 0, true, false, false, false, false, false, false, false, false, true},
  {35, "Display Rotate",   0,    3,   1, 0, true, false, false, false, false, false, true}
}

local selected = 1
local scroll = 1
local editing = false
local connected = false
local lastRx = 0
local nextRequest = 0
local requestIndex = 1
local nextGainRequest = 0
local nextCalibrationRequest = 0
local pushFailed = 0
local pushedThisFrame = false

local function push(command, payload)
  if not crossfireTelemetryPush or pushedThisFrame then return false end
  pushedThisFrame = true
  if crossfireTelemetryPush(command, payload) then return true end
  pushFailed = getTime()
  return false
end

local function readInt32(data, index)
  local value = data[index] * 16777216
              + data[index + 1] * 65536
              + data[index + 2] * 256
              + data[index + 3]
  if value >= 2147483648 then value = value - 4294967296 end
  return value
end

local function int32Bytes(value)
  if value < 0 then value = value + 4294967296 end
  local b1 = math.floor(value / 16777216) % 256
  local b2 = math.floor(value / 65536) % 256
  local b3 = math.floor(value / 256) % 256
  local b4 = value % 256
  return b1, b2, b3, b4
end

local function requestField(field)
  if field == nil then return false end
  return push(0x2C, {DEVICE, RADIO, field[1], 0})
end

local function writeField(field)
  if field.value == nil then return end
  if field[7] then
    push(0x2D, {DEVICE, RADIO, field[1], field.value})
  else
    local b1, b2, b3, b4 = int32Bytes(field.value)
    push(0x2D, {DEVICE, RADIO, field[1], b1, b2, b3, b4})
  end
end

local function findField(id)
  for i = 1, #fields do
    if fields[i][1] == id then return fields[i] end
  end
  return nil
end

local function consumeTelemetry()
  if not crossfireTelemetryPop then return end
  while true do
    local command, data = crossfireTelemetryPop()
    if command == nil then break end

    if command == 0x2B and #data >= 7 and data[1] == RADIO and data[2] == DEVICE then
      local field = findField(data[3])
      if field then
        local keepValue = editing and field == fields[selected]
        local dataType = data[6]
        local index = 7
        while index <= #data and data[index] ~= 0 do index = index + 1 end
        index = index + 1

        if dataType == 0x08 and index + 3 <= #data then
          if not keepValue then field.value = readInt32(data, index) end
        elseif dataType == 0x09 then
          while index <= #data and data[index] ~= 0 do index = index + 1 end
          index = index + 1
          if index <= #data and not keepValue then field.value = data[index] end
          if index + 2 <= #data then
            field[3] = data[index + 1]
            field[4] = data[index + 2]
          end
        end
        connected = true
        lastRx = getTime()
      end
    elseif command == 0x2D and #data >= 4 and data[1] == RADIO and data[2] == DEVICE then
      local field = findField(data[3])
      if field then
        local keepValue = editing and field == fields[selected]
        if field[7] then
          if not keepValue then field.value = data[4] end
        elseif #data >= 7 and not keepValue then
          field.value = readInt32(data, 4)
        end
        connected = true
        lastRx = getTime()
      end
    end
  end
end

local function valueText(field)
  if field.value == nil then return "---" end
  if field[10] then
    if field.value == 2 then return "YES" end
    if field.value == 1 then return "PARTIAL" end
    return "NO"
  end
  if field[11] then return "PRESS" end
  if field[12] then
    if field.value == 2 then return "OFF" end
    if field.value == 1 then return "120 Hz" end
    return "24 Hz"
  end
  if field[13] then
    if field[4] == 1 then return field.value == 0 and "NORMAL" or "180 DEG" end
    if field.value == 1 then return "90 CW" end
    if field.value == 2 then return "180 DEG" end
    if field.value == 3 then return "90 CCW" end
    return "0 DEG"
  end
  if field[14] then return field.value == 0 and "1/10" or "MICRO" end
  if field[16] then
    if field.value == 2 then return "333 Hz" end
    if field.value == 1 then return "250 Hz" end
    return "50 Hz"
  end
  if field[8] then
    if field[4] == 0 then return "RES" end
    return field.value == 0 and "OFF" or "CH" .. tostring(field.value)
  end
  if field[9] then return field.value == 0 and "250 Hz" or "333 Hz" end
  if field[7] then return field.value == 0 and "OFF" or "ON" end
  local decimals = field[6]
  if decimals == 0 then return tostring(field.value) end
  local scale = 10 ^ decimals
  return string.format("%." .. decimals .. "f", field.value / scale)
end
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

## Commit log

2026-08-28 Release OpenDrift v1.0.7 anti-wobble control
    [OpenDrift Pdb.kicad_pcb, OpenDrift Pdb.kicad_sch]
2026-08-30 Release v1.0.7b steering calibration workflow
2026-08-30 Release v1.0.7c physical servo endpoints
2026-08-31 Add low-latency gyro test modes and correction authority fix
    [OpenDrift.lua, main.cpp]
2026-09-25 Advance control precision and add Matrix support
    Add driver-priority and transition control refinements, high-resolution steering and throttle outputs, selectable ESC rates, micro anti-wobble tuning, safer calibration and failsafes, WiFi recovery, display controls, and private Waveshare S3 Matrix PWM/CRSF targets.
    Credits: incorporates selected QoL and reliability concepts from J3vb's PR #4, plus driver-priority and control-loop analysis contributed by uarenotreal.
    [partitions_matrix.csv]
2026-09-25 Smooth gyro correction return to center
2026-09-26 Stop wobble zero-crossings from arming the transition phase
    The chassis reversal trigger fired on every swing of a wobble around zero
    yaw. Each swing reset the 0.18 s transition timer, so a 2.5-4 Hz wobble
    kept the controller in the transition phase almost permanently. That
    blocked Anti Wobble tracking and held its notch at the 20 percent guard
    depth at any setting, cut the prediction lead, and engaged the transition
    slew, which adds lag. The wobble was left undamped, or made worse,
    whatever Anti Wobble was set to.
    A reversal now only counts after the old direction was held for 0.25 s,
    longer than the slowest wheel-wobble half cycle the hunt detector accepts
    (0.23 s). Real drift transitions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
2026-10-01 Make the WiFi access point easier to connect to
    - Default-named units broadcast OpenDrift-XXXX (per-board suffix) so
    several cars at one track no longer share one network name.
    - Pick the quietest of channels 1/6/11 with a short scan at startup
    instead of always using channel 1.
    - Force a 20 MHz channel so band-hopping 2.4 GHz RC links clash less.
    - Wait at least 3 minutes for the first phone before auto-off; the
    40 s default used to shut WiFi off before most users connected.
    - Show the broadcast name on the displays, boot log and web page.
    Claude-Session: https://claude.ai/code/session_01AaMbhYMQ1fNAKNp17whq5d
    [main.cpp]
